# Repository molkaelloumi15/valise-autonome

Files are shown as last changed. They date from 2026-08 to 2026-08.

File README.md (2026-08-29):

# 🧳 Valise Autonome

Projet académique (2ᵉ année d'ingénieur, ENSIT, 2024–2025) réalisé en binôme (Molka Elloumi & Fakhri Menjli) : une valise connectée capable de **suivre automatiquement son propriétaire**, d'**éviter les obstacles**, et pilotable via une **application mobile Flutter**.

## 🎯 Fonctionnalités principales

| Fonctionnalité | Description |
|---|---|
| **Suivi autonome** | La valise détecte la position de son propriétaire en temps réel et le suit automatiquement. |
| **Navigation & évitement d'obstacles** | Détection et contournement des obstacles fixes et mobiles à l'aide de capteurs ultrasoniques. |
| **Mode manuel** | Contrôle manuel de la valise depuis l'application mobile. |
| **Notifications** | Alerte envoyée au smartphone en cas de perte de connexion avec la valise. |
| **Autonomie** | Batterie lithium-ion dimensionnée pour au moins 8h d'utilisation continue. |

## 🧠 Principe de fonctionnement

La valise embarque un microcontrôleur **ESP32** qui :
1. Estime la distance au smartphone du propriétaire à partir de la puissance du signal Wi-Fi (RSSI).
2. Mesure en parallèle la distance aux obstacles via un capteur ultrasonique.
3. Compare les deux mesures pour distinguer un vrai obstacle d'un simple éloignement du propriétaire, et ajuste le déplacement des moteurs en conséquence.
4. Expose ces données via un petit serveur web embarqué (mode point d'accès Wi-Fi), interrogé par l'application mobile.

## 🛠️ Stack technique

- **Firmware** : C++ (Arduino), ESP32, capteurs ultrasoniques HC-SR04, moteurs CC à engrenages FIT0564
- **Électronique** : PCB personnalisé conçu sous **KiCad**, prototypage sous **Proteus 8 ISIS**
- **Application mobile** : **Flutter** (architecture MVVM) — authentification, écran d'accueil, suivi en temps réel, réglages
- **Outils** : Arduino IDE, VS Code, KiCad

## 📂 Structure du dépôt

```
.
├── firmware/           # Code embarqué ESP32 (Arduino)
│   └── valise_autonome.ino
├── circuit/             # Conception électronique (KiCad)
│   ├── circuit.kicad_sch / .kicad_pcb / .kicad_pro
│   └── gerbers/          # Fichiers de fabrication (Gerber/drill)
├── mobile-app/          # Application Flutter (code source Dart)
│   ├── lib/
│   │   ├── main.dart
│   │   ├── screens/      # Login, Home, Profil, Réglages
│   │   └── services/     # Authentification, communication ESP32
│   ├── assets/
│   └── pubspec.yaml
└── docs/
    └── Valise_autonome.pdf   # Rapport de projet complet
```

## 📄 Documentation complète

Le rapport de projet complet (cahier des charges, étude de l'existant, architecture, choix techniques, résultats de tests) est disponible dans [`docs/Valise_autonome.pdf`](docs/Valise_autonome.pdf).

## 🚀 Pour reproduire le firmware

1. Ouvrir `firmware/valise_autonome.ino` dans l'Arduino IDE avec le support ESP32 installé.
2. Flasher la carte ESP32.
3. Se connecter au réseau Wi-Fi `Suitcase_AP` créé par la valise.
4. Lancer l'application Flutter (`mobile-app/`) pour piloter et suivre la valise.

---

*Projet réalisé dans le cadre de la formation d'ingénieur à l'ENSEA — Molka Elloumi, [LinkedIn](https://linkedin.com/in/molkaelloumi)*

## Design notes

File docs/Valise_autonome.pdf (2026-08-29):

# Rapport de Projet

de

# Deuxième année du premier semestre

Présenté et soutenu publiquement le 10/12/2024

Par

# ELLOUMI Molka MENJLI Fakhri

# Valise Autonome

### Membre du jury

### Monsieur

### Monsieur

### JEBRI Ayoub

### SIMOND Nicolas

### Année universitaire : 2024-2025

# Table des matières

Introduction générale | 1
Chapitre 1: | Gestion de Projet | 2
Chapitre 2: | Environnement de travail | 7

i

Table des matières | Table des matières
Chapitre 3: | ARCHITECTURE DU SYSTÈME | 15
Chapitre 4: | Réalisation logicielle | 18
Chapitre 5: | Réalisation matérielle | 27

ii

Table des matières | Table des matières
Bibliographie | 40

iii

# Table des figures

1.1 Diagramme de Gantt global de la deuxième phase du projet | | 6
2.1 Le microcontrôleur ESP32 | | 8
2.2 Moteurs CC à engrenages FIT0564 | | 9
2.3 Capteur ultrasonique SH04 | | 9
2.4 PCB personnalisé | 10
2.5 batterie 12v | 11
2.6 Proteus 8 ISIS | 11
2.7 Arduino IDE | 12
2.8 Flutter | 12
2.9 KiCad | 13
2.10 VS Code | 13
3.1 Schéma d’architecture globale du système | 15
4.1 Aperçu des résultats de tests | 21
4.2 Diagramme de cas d’utilisation de l’application mobile Flutter | 22
4.3 Architecture MVVM utilisée dans notre application Flutter | 23
4.4 Structure des fichiers de l’application Flutter | 24
4.5 Exemple de contrôle de saisie dans l’écran de connexion | 25
4.6 Interface principale de suivi (hors connexion) | 26
5.1 Arrêt du moteur lorsque PWM1 et PWM2 sont nuls | 28
5.2 Fonctionnement avec PWM1 actif | 28
5.3 Fonctionnement avec PWM2 actif | 28
5.4 Fonctionnement avec PWM1 et PWM2 actifs | 28

iv

Table des figures | Table des figures
5.5 Tableau récapitulatif du fonctionnement du notre controlleur | | 28
5.6 Simulation : Contrôle bidirectionnel du moteur | 30
5.7 Essai du circuit de contrôle moteur | 31
5.8 Routage du PCB sur KiCad | 32
5.9 largeur des pistes | 33
5.10 les tests | 34
5.11 Capteur ultrasonique SH04 | 36

v

# Introduction générale

Le projet de valise autonome vise à répondre aux besoins des voyageurs dans des environnements

variés comme les aéroports, les gares ou les trottoirs. Cette innovation cherche à réduire les

efforts physiques liés au transport des bagages tout en améliorant la mobilité et le confort des

utilisateurs. Avec l’évolution des technologies de navigation et de suivi, ce projet explore une

solution autonome qui combine électronique avancée et intelligence embarquée pour offrir une

expérience pratique et innovante.

### Chapitre 1

# Gestion de Projet

## Introduction

Ce chapitre du projet présente la gestion de notre travail. Nous y détaillons tout d’abord le

cahier des charges, suivi d’une étude des solutions existantes sur le marché, qui nous a permis

de nous inspirer tout en identifiant leurs limites. Nous proposons ensuite notre solution et

terminons par l’élaboration du diagramme de Gantt pour la première phase du projet, puis

celui relatif à la seconde phase.

## 1 Cahier des Charges

Dans cette section, nous allons parler du cahier des charges. À partir du sujet proposé, nous

avons pu déterminer ses fonctionnalités obligatoires et élaborer un cahier des charges servant

de référence pour notre travail. Nous avons également élaboré le tableau ci-dessous. Ce tableau

comporte les fonctionnalités, leur expression, les critères, et les moyens de contrôle.

— Expression : il s’agit de l’explication de la fonctionnalité.

— Critères : ils désignent les conditions ou exigences spécifiques que la fonctionnalité doit

remplir pour être considérée comme réussie. Un critère représente ce qui est attendu

comme résultat pour vérifier la fonctionnalité.

— Moyens de contrôle : ce sont les outils ou méthodes permettant de s’assurer que les

critères sont respectés.

Chapitre 1. Gestion de Projet | 2. Étude de l’Existant
Fonctionnalité (FP) | Expression | Critères | Moyen de Contrôle
FP1 : Suivi Au-tonome | Permettre à la valise de suivre automatiquement son propriétaire. | La valise doit détec-ter la position du propriétaire en temps réel. | Capteurs ultraso-niques, un module wifi intégré dans la carte ESP32, et les moteurs.
FP2 : Naviga-tion | Naviguer de manière auto-nome dans différents envi-ronnements. | Capacité à détecter et à éviter des obstacles immobiles et mobiles. | Capteurs ultraso-niques, un module wifi intégré dans la carte ESP32 et les moteurs.
FP3 : Mode Manuel | Permettre le contrôle ma-nuel de la valise. | Le mode manuel doit être activé facilement et rapidement. | Interface utilisateur (boutons, applica-tion).
FP4 : Notifica-tions | Envoyer des alertes au pro-priétaire en cas de perte de connexion. | Notification sur smartphone en cas de perte de connexion. | WIFI
FP5 : Autono-mie de la Bat-terie | Fonctionner sans recharge fréquente. | Autonomie d’au moins 8 heures en utilisation normale. | Batterie lithium-ion

Table 1.1 – Spécifications des fonctionnalités principales du projet

## 2 Étude de l’Existant

Après des recherches, nous avons pu identifier trois solutions similaires à notre projet. Bien

que nous n’ayons pas trouvé de références techniques, nous avons trouvé des descriptions des

technologies utilisées, ce qui nous a aidés à mieux comprendre. Voici un tableau qui donne un

aperçu de ces solutions en présentant précisément les technologies utilisées, leurs avantages et

leurs inconvénients.

Solution | Technologie Utili-sée | Avantages | Inconvénients
Valise Ovis | Suivi par caméra et IA | - Suivi précis et intelli-gent - Bonne navigation dans les environnements ou-verts | - Très coûteuse (prix élevé). - Autonomie limitée (batterie).

Chapitre 1. Gestion de Projet | 3. Limites des Solutions Existantes
Valise Travel-mate | Suivi par Blue-tooth (RSSI) | - Faible coût relatif - Facile à mettre en œuvre | - Navigation imprécise en cas d’obstacles. - Portée limitée de la connexion Bluetooth.
Valise Cowaro-bot | Capteurs ultraso-niques et LiDAR | - Excellente détection d’obstacles - Bonne autonomie de batterie | - Lourde et coûteuse. - Complexité dans la maintenance.

## 3 Limites des Solutions Existantes

À travers cette analyse, nous constatons que :

— Le coût élevé des solutions comme Ovis ou Cowarobot limite leur accessibilité.

— Les technologies basées uniquement sur le Bluetooth montrent des limites en termes de

portée et de précision.

— Les systèmes complexes intégrant des caméras IA ou LiDAR augmentent la consomma-

tion énergétique, ce qui réduit l’autonomie de la batterie.

Nous avons pu, à travers ces observations, élaborer notre solution en tenant compte de nos

contraintes, tout en envisageant d’apporter des améliorations et des optimisations. Notre solu-

tion doit :

— Utiliser des technologies abordables .

— Maintenir un coût réduit tout en respectant les contraintes techniques et budgétaires.

— Assurer une autonomie énergétique satisfaisante en intégrant une batterie adaptée.

## 4 Proposition de Notre Solution

Pour mieux présenter ce que nous souhaitons réaliser, nous avons élaboré un tableau qui résume

comment chaque fonctionnalité discutée dans le cahier des charges sera satisfaite technologique-

ment à travers la solution technologique proposée, ainsi qu’une justification brève de ce choix,

tout en respectant une contrainte budgétaire stricte.

Chapitre 1. Gestion de Projet5. Analyse Comparative : Solutions Existantes vs Notre Solution

Composant | Technologie Choisie | Justification
Suivi du propriétaire | Wi-Fi (RSSI) | Solution abordable et plus ro-buste que Bluetooth pour une communication fiable.
Détection d’obstacles | Capteurs ultraso-niques HC-SR04 | Solution abordable et fiable pour la navigation et la détection d’obstacles.
Navigation et contrôle | Microcontrôleur ESP32 | Intègre Wi-Fi pour la commu-nication et Bluetooth comme option secondaire, à faible coût.
Propulsion | Moteurs CC avec un contrôleur | Économique, fiable et facile à contrôler.
Alimentation | Batterie lithium-ion rechargeable | Offre une bonne autonomie pour une utilisation prolongée avec un poids réduit.

Table 1.3 – Composants et technologies choisis pour la solution

## 5 Analyse Comparative : Solutions Existantes vs Notre Solu-

## tion

Finalement, nous avons réalisé ce tableau récapitulatif qui met en valeur ce que nous avons

amélioré par rapport aux autres solutions.

Critère | Valise Ovis | Valise Travel-mate | Notre Solution
Technologie de Suivi | IA + Caméra | Bluetooth | Wifi (RSSI)
Technologie de Navi-gation | Caméras/LiDAR | Capteurs ba-siques | Capteurs ultra-soniques HC-SR04
Coût | Très élevé | Modéré | Abordable
Autonomie | Moyenne | Bonne | Optimisée avec batterie Li-Ion
Précision de Suivi | Élevée | Faible | Moyenne (amé-liorable par op-timisation)

Chapitre 1. Gestion de Projet | 6. Diagramme de Gantt

Facilité de mise en

œuvre

Complexe | Simple | Simple

## 6 Diagramme de Gantt

Le diagramme de Gantt est un outil de planification visuelle permettant de structurer les

tâches d’un projet dans le temps. Pour la seconde phase de notre projet, nous avons élaboré un

diagramme global afin de définir les différentes étapes prévues et organiser leur déroulement.

Cependant, en raison de divers problèmes techniques et de contraintes rencontrés en cours de

réalisation, nous n’avons pu mener à bien que les trois dernières tâches planifiées.

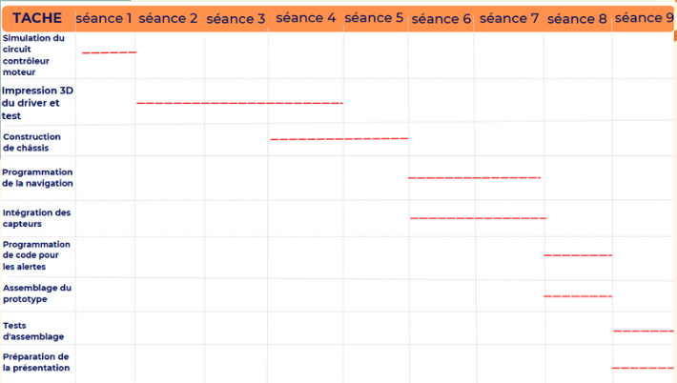
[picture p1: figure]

Figure 1.1 – Diagramme de Gantt global de la deuxième phase du projet

## Conclusion

Ce chapitre a permis de présenter les grandes lignes de notre projet, d’introduire notre cahier des

charges ainsi que notre réflexion autour de la solution retenue. Nous avons également expliqué

notre planification, tout en précisant les limites rencontrées lors de la mise en œuvre. Le chapitre

suivant détaillera l’environnement matériel et logiciel utilisé pour concrétiser notre solution.

### Chapitre 2

# Environnement de travail

## Introduction

Ce chapitre décrit les différents environnements de travail, tant matériels que logiciels, qui

ont été nécessaires à la réalisation de ce projet. Ces environnements ont été soigneusement

sélectionnés pour répondre aux exigences techniques et fonctionnelles de la solution envisagée.

## 1 Environnement matériel

Pour la conception et la réalisation de la valise autonome, plusieurs éléments matériels ont été

utilisés :

### 2.1.1 Le microcontrôleur ESP32

Le microcontrôleur ESP32 a été choisi pour ses performances élevées en termes de traitement et

de connectivité. Il dispose d’un processeur double cœur, d’une connectivité Wi-Fi et Bluetooth

intégrée, ce qui le rend idéal pour gérer les communications sans fil et les interactions avec les

capteurs et les moteurs. Sa faible consommation énergétique et son large écosystème de support

logiciel en font un choix fiable pour les applications embarquées.

Chapitre 2. Environnement de travail | 1. Environnement matériel

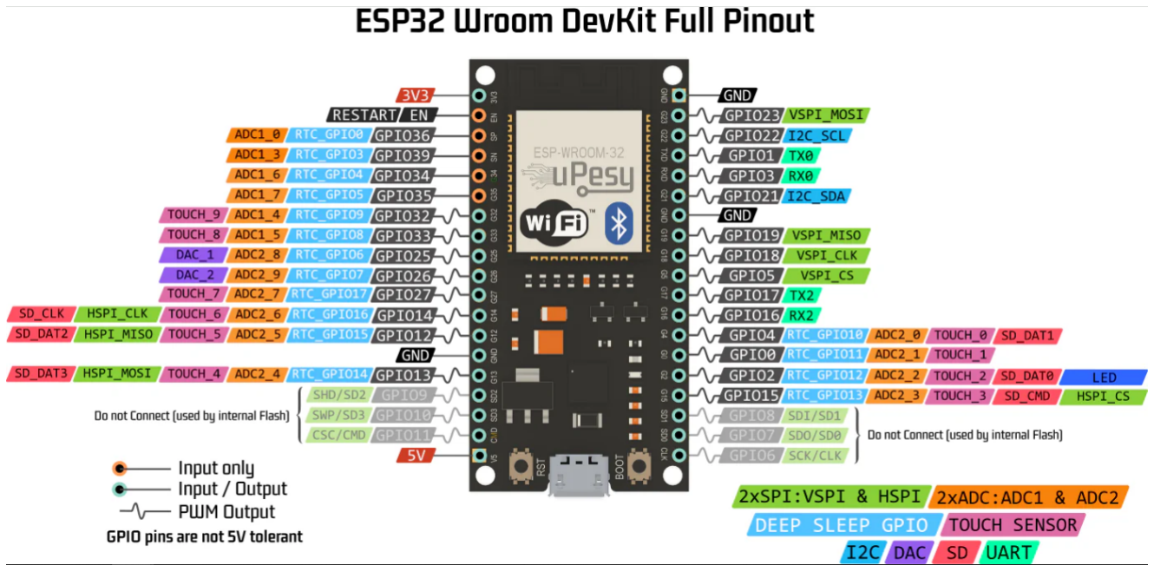
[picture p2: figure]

Figure 2.1 – Le microcontrôleur ESP32

### 2.1.2 Moteurs CC à engrenages FIT0564

Ces moteurs à courant continu avec réducteur intégré offrent une combinaison idéale de puis-

sance et de précision. Le réducteur permet de fournir un couple élevé, nécessaire pour déplacer

la valise, tout en maintenant une vitesse contrôlée. Leur robustesse et leur durabilité en font

un choix adapté pour une utilisation prolongée dans des conditions variées.

Table 2.1 – Étude mathématique pour le choix du moteur

Étape | Prototype (1 kg) | Cas réel (23 kg)
1. Force exercée par la charge | f=m*g =9.81 N | f = m ∗ g = 225.63 N
2. Couple | C = f ∗ r = 0.4905 Nm | C = f ∗ r = 11.2815Nm
3. Vitesse angulaire | N = 2π0.05 ≈ 134.5 tr/min 1.460 N = 2π
4. Puissance | P = 6.91 W | P = 159 W
5. Courant | I = V = P 6.91 12 ≈ 0.7 A | I = V = P 159 48 ≈ 3 A
6. Durée de fonction-nement | capacité 9 t = courant = 1.15 ≈ 8 heures | capacité 18 t = courant = 3 ≈ 6 heures
60 ≈ 14.1 rad/s | N =

1.460
2π0.05 ≈ 134.5 tr/min

Les calculs ci-dessus ont été réalisés afin de choisir le moteur adapté en prenant en compte la

force, le couple, la vitesse angulaire, la puissance nécessaire et l’autonomie énergétique.

Chapitre 2. Environnement de travail | 1. Environnement matériel

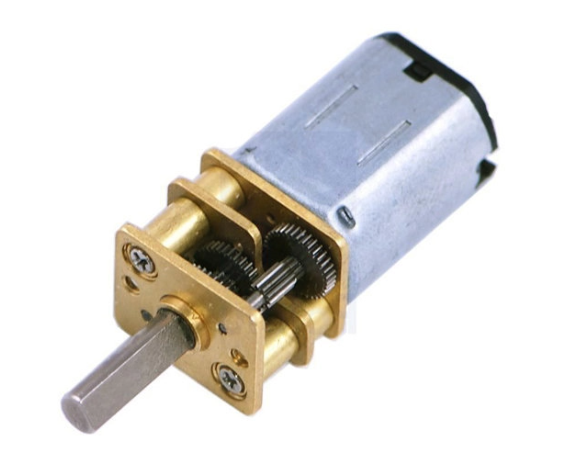
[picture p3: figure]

Figure 2.2 – Moteurs CC à engrenages FIT0564

### 2.1.3 Capteur ultrasonique SH04

Ce capteur est utilisé pour mesurer les distances grâce à l’émission et la réception d’ondes

ultrasoniques. Avec une portée précise allant jusqu’à plusieurs mètres, il permet à la valise de

détecter et d’éviter les obstacles tout en suivant son propriétaire. Sa simplicité d’intégration et

sa fiabilité en font un composant essentiel pour la navigation autonome.

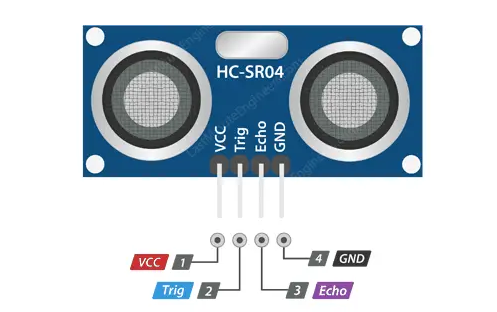
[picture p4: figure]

Figure 2.3 – Capteur ultrasonique SH04

### 2.1.4 Contrôleur de moteur (PCB personnalisé)

Le contrôleur de moteur est un circuit imprimé conçu spécifiquement pour ce projet. Il intègre

un hacheur à quatre quadrants, permettant de contrôler à la fois la vitesse et le sens de rotation

des moteurs. Ce circuit a été conçu pour offrir une grande précision et une efficacité énergétique

optimale. Sa conception sur mesure garantit une compatibilité parfaite avec les moteurs et les

autres composants du système.

Chapitre 2. Environnement de travail | 1. Environnement matériel

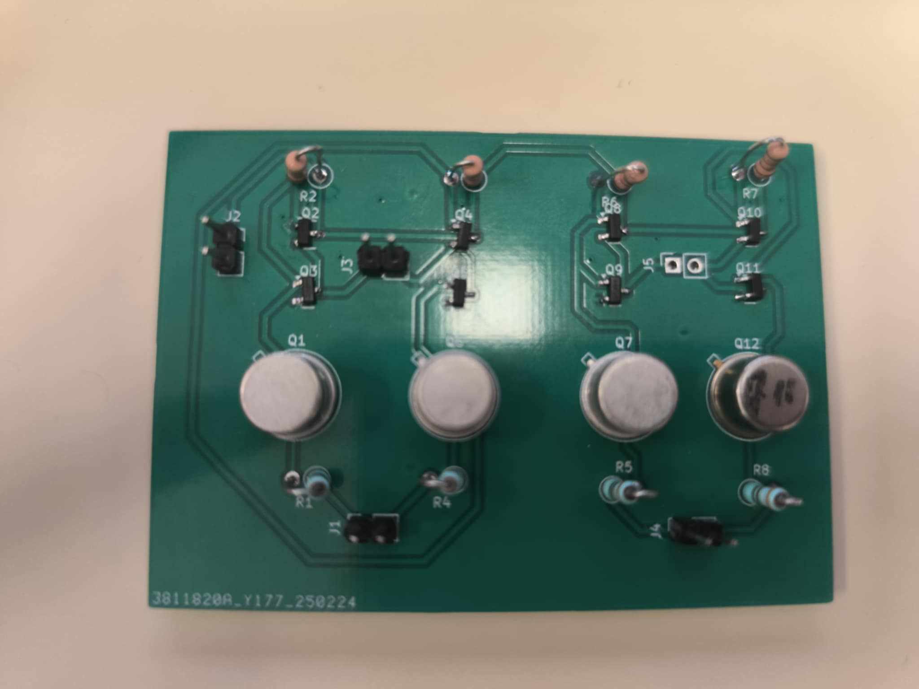
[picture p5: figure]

Figure 2.4 – PCB personnalisé

### 2.1.5 Alimentation

L’alimentation de la valise autonome repose sur deux systèmes distincts : une batterie Li-ion

pour alimenter la carte ESP32 et les capteurs, et une batterie 12V pour les moteurs.

Batterie Li-ion

Cette batterie, d’une capacité suffisante, alimente la carte ESP32 et les capteurs. Elle est

choisie pour sa haute densité énergétique, permettant une autonomie prolongée. Un régulateur

de tension permet de convertir la sortie de la batterie Li-ion (3.7V) en 3.3V pour l’ESP32.

Batterie 12V

Elle est utilisée pour alimenter les moteurs et le contrôleur de moteur. Cette batterie est di-

mensionnée pour fournir une autonomie suffisante lors des déplacements de la valise.

Chapitre 2. Environnement de travail | 2. Environnement logiciel

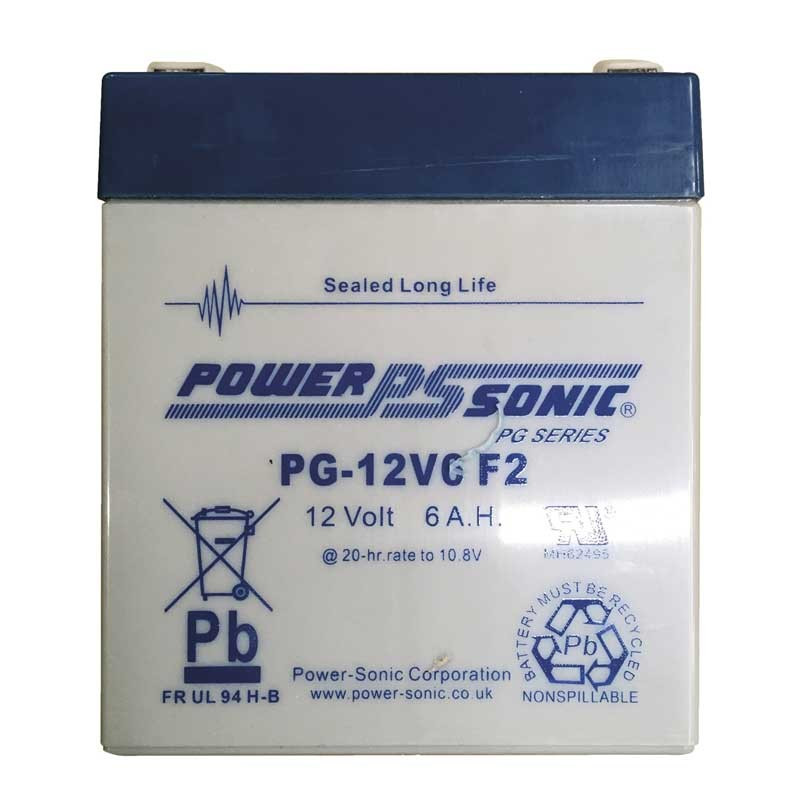
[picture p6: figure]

Figure 2.5 – batterie 12v

## 2 Environnement logiciel

Le développement et la simulation du projet ont nécessité l’utilisation de deux outils logiciels :

### 2.2.1 Proteus 8 ISIS

Cet outil a été employé pour la conception et la simulation des circuits électroniques. Grâce à sa

capacité de simuler des composants en temps réel, il a permis de tester et d’optimiser le schéma

du contrôleur de moteur avant sa fabrication. La simulation a inclus des tests de tension, de

courant et de réponse dynamique des circuits.

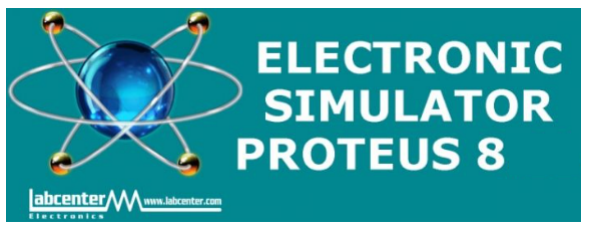
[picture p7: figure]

Figure 2.6 – Proteus 8 ISIS

Chapitre 2. Environnement de travail | 2. Environnement logiciel

### 2.2.2 Arduino IDE

L’Arduino Integrated Development Environment (IDE) a été utilisé pour écrire, compiler et

téléverser le code sur l’ESP32. Cet outil propose une interface intuitive qui simplifie le déve-

loppement grâce à une vaste bibliothèque de fonctions prêtes à l’emploi, comme la gestion des

capteurs, des moteurs et de la connectivité. L’IDE offre également un moniteur série intégré,

utile pour le débogage en temps réel des fonctionnalités du système.

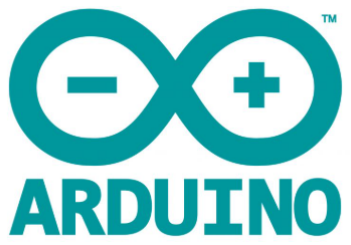
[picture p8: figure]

Figure 2.7 – Arduino IDE

### 2.2.3 Flutter

Flutter est un framework open source développé par Google permettant de créer des applications

mobiles multiplateformes. Dans le cadre de ce projet, Flutter a été utilisé pour développer une

application mobile Android servant d’interface de communication avec la valise autonome.

Grâce à son langage Dart et son environnement de développement intégré, Flutter a permis de

concevoir des interfaces utilisateur modernes et réactives.

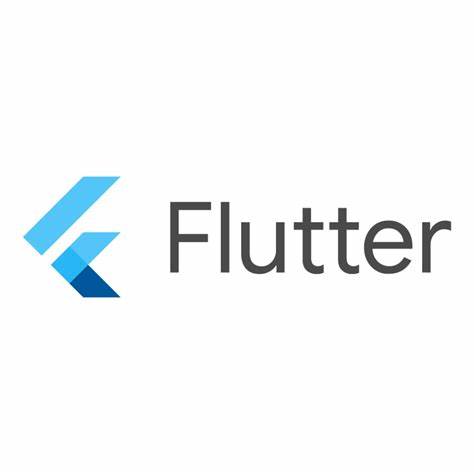
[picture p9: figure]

Figure 2.8 – Flutter

Chapitre 2. Environnement de travail | 2. Environnement logiciel

### 2.2.4 KiCad

KiCad est un logiciel de conception assistée par ordinateur (CAO) libre utilisé pour concevoir

des circuits imprimés (PCB). Dans notre projet, KiCad a été utilisé pour la réalisation du

schéma électrique et du routage du PCB du contrôleur moteur bidirectionnel.

Figure 2.9 – KiCad

### 2.2.5 Visual Studio Code (VS Code)

Visual Studio Code est un éditeur de code multiplateforme largement utilisé pour le dévelop-

pement embarqué. Dans notre projet, il a été utilisé pour écrire et organiser le code destiné

à l’ESP32, notamment à l’aide de l’extension PlatformIO, qui offre une meilleure gestion des

projets et des dépendances que l’IDE Arduino.

VS Code a également permis d’éditer les scripts en Dart pour Flutter, de tester les requêtes

HTTP, et de configurer les paramètres réseau du projet. Son interface moderne et ses nom-

breuses extensions ont grandement facilité le processus de développement et de débogage.

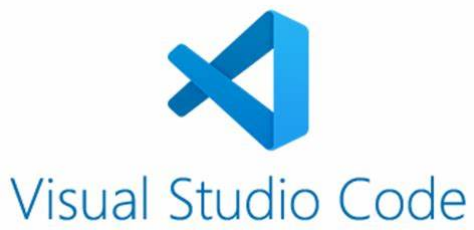
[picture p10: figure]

Figure 2.10 – VS Code

## Conclusion

Nous avons bien décrit dans ce chapitre l’environnement de travail mis en place pour ce projet,

qui repose sur une combinaison d’équipements matériels robustes et d’outils logiciels perfor-

Chapitre 2. Environnement de travail | 2. Environnement logiciel

mants. Dans le prochain chapitre, nous aborderons l’architecture de notre valise.

### Chapitre 3

# ARCHITECTURE DU SYSTÈME

## Introduction

Ce chapitre présente l’architecture globale de la solution technique mise en place pour la réa-

lisation de la valise autonome. Nous y décrivons l’organisation matérielle et logicielle, les flux

de communication entre les différents modules, ainsi que le fonctionnement global du système.

Une attention particulière est portée à l’interaction avec l’utilisateur, qui reçoit en temps réel

des informations cruciales via l’application mobile Flutter.

## 1 Schéma d’ensemble

Le diagramme suivant illustre l’interaction entre les principaux composants matériels et leur

rôle dans le fonctionnement de la valise autonome.

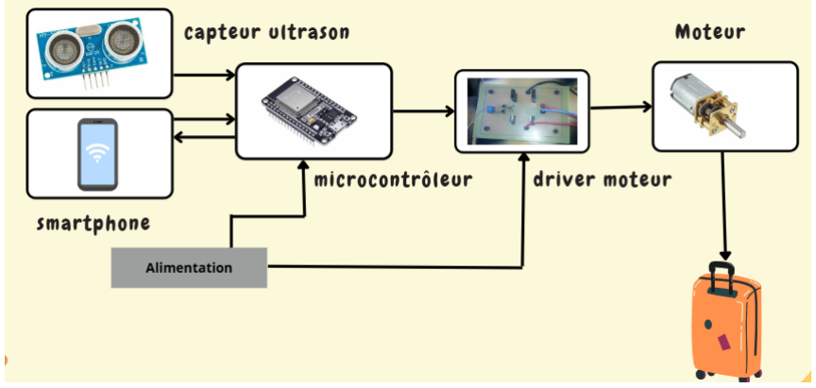
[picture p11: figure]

Figure 3.1 – Schéma d’architecture globale du système

Chapitre 3. ARCHITECTURE DU SYSTÈME | 2. Flux de Communication

Les éléments principaux du système sont :

— Microcontrôleur (ESP32) : Coordonne le système en traitant les données des capteurs

et en contrôlant les moteurs.

— Capteurs ultrasoniques : Détectent les obstacles à proximité et transmettent les dis-

tances au microcontrôleur.

— Contrôleur de moteur : Régule la puissance et la direction des moteurs selon les ins-

tructions du microcontrôleur.

— Moteurs à engrenages CC : Assurent le mouvement et la direction de la valise.

— Connexion WiFi : Permet la communication entre la valise et le smartphone de l’utili-

sateur.

— Batterie lithium-ion : Fournit l’énergie nécessaire au fonctionnement des composants.

## 2 Flux de Communication

Les flux de données entre les différents composants garantissent le fonctionnement global du

système. Voici la séquence des échanges :

1. Capteurs vers Microcontrôleur : Les capteurs ultrasoniques mesurent les distances aux

obstacles et envoient les informations au microcontrôleur (ESP32).

2. Microcontrôleur vers Contrôleur de Moteur : Le microcontrôleur analyse les données

reçues et envoie des instructions précises au contrôleur pour ajuster la vitesse et la

direction des moteurs.

3. Contrôleur de Moteur vers Moteurs : Le contrôleur de moteur régule la puissance

fournie aux moteurs pour exécuter les commandes du microcontrôleur (mouvement, arrêt

ou changement de direction).

4. Microcontrôleur vers Application Smartphone : Le microcontrôleur utilise la connexion

WiFi pour transmettre des informations essentielles à l’application Flutter installée sur

le smartphone de l’utilisateur. Cette communication inclut :

— le statut de la connexion entre la valise et l’utilisateur (valise connectée ou perdue),

— la distance estimée entre la valise et le smartphone (via RSSI),

— la détection éventuelle d’un obstacle (via le capteur ultrasonique).

L’application affiche ces informations de manière intuitive, permettant à l’utilisateur

de réagir rapidement en cas de problème et de suivre la position de la valise en toute

simplicité.

Chapitre 3. ARCHITECTURE DU SYSTÈME | 3. Fonctionnement Global de la Valise

## 3 Fonctionnement Global de la Valise

L’algorithme global qui régit le fonctionnement de la valise peut être décrit en quatre étapes

principales :

1. Détection et Connexion WiFi : La valise établit une connexion WiFi avec le smartphone

de l’utilisateur. Le microcontrôleur récupère en continu les informations sur la densité

du signal WiFi pour estimer la position relative du propriétaire.

2. Suivi de la Direction : Si le signal WiFi diminue, la valise détecte qu’elle s’éloigne et

ajuste sa trajectoire en conséquence. Les moteurs à engrenages CC sont commandés pour

corriger la direction.

3. Gestion des Obstacles : Les capteurs ultrasoniques mesurent en temps réel les distances

avec les obstacles environnants. En cas de détection, le microcontrôleur ajuste les moteurs

pour éviter la collision.

4. Mise à Jour de la Direction : La valise combine les informations des capteurs et du

signal WiFi pour corriger continuellement sa trajectoire, assurant ainsi un suivi fluide et

sécurisé.

## Conclusion

Ce chapitre a présenté l’architecture globale du système, en mettant en lumière les interactions

entre les composants matériels, logiciels, et l’utilisateur. L’intégration de l’application Flutter

assure une communication bidirectionnelle efficace, permettant à la valise d’agir et d’informer

l’utilisateur en temps réel sur sa position, la connexion et les obstacles. Le chapitre suivant

abordera la réalisation logicielle du projet.

### Chapitre 4

# Réalisation logicielle

## Introduction

Ce chapitre détaille le développement logiciel du projet, depuis la programmation embarquée

sur l’ESP32 jusqu’à la création de l’application mobile Flutter. Nous y expliquons les logiques

de traitement, de communication et d’affichage mises en place.

## 1 Programmation embarquée de l’ESP32

La programmation de la carte ESP32 constitue le cœur du système embarqué de la valise

autonome. Elle permet à la valise de percevoir son environnement, de prendre des décisions de

navigation, et de transmettre les informations nécessaires à l’application mobile Flutter. Les

principales fonctionnalités mises en œuvre sont les suivantes :

### 4.1.1 Lecture des capteurs

Deux types de capteurs sont utilisés :

— Le capteur ultrasonique Les données du capteur ultrasonique sont récupérées régulière-

ment afin de détecter les obstacles et ajuster la trajectoire.

— Le signal RSSI WiFi est utilisé pour estimer la distance entre le smartphone de l’utili-

sateur et la valise, à partir de la puissance du signal WiFi reçu.

Chapitre 4. Réalisation logicielle | 1. Programmation embarquée de l’ESP32

### 4.1.2 Estimation de la distance via le RSSI

Le RSSI (Received Signal Strength Indicator) est un indicateur de la puissance du signal WiFi

reçu par l’ESP32. Il est exprimé en dBm. Une valeur plus proche de zéro indique un signal plus

fort. Dans notre projet, il est utilisé pour :

— Estimer la distance entre la valise et le smartphone du propriétaire.

— Déterminer si la valise doit s’approcher, rester sur place, ou signaler une perte de

connexion.

Formule de calcul de distance :

d = 10

A−RSSI
10n | (4.1)

où :

— d : distance en mètres,

— A : RSSI à 1 mètre,

— n : facteur d’atténuation (selon l’environnement),

— RSSI : signal mesuré (en dBm).

### 4.1.3 Logique de navigation intelligente

La logique de navigation de la valise repose sur l’interprétation croisée des données issues de

deux sources : le signal RSSI (Received Signal Strength Indicator) et le capteur ultrasonique.

L’objectif est de permettre à la valise de suivre son utilisateur tout en évitant les obstacles, de

manière autonome et réactive.

Voici le fonctionnement général de l’algorithme embarqué :

— Lorsque la valise est suffisamment proche de l’utilisateur (selon la valeur du RSSI), elle

reste immobile.

— Si le RSSI indique un éloignement (signal plus faible), la valise se met en mouvement

pour réduire la distance avec son propriétaire.

— Pendant le déplacement, la valise utilise le capteur ultrasonique pour détecter tout obs-

tacle présent sur son trajet.

— Si un obstacle est détecté, la valise interrompt immédiatement son mouvement et ajuste

sa direction pour le contourner.

Chapitre 4. Réalisation logicielle | 1. Programmation embarquée de l’ESP32

### 4.1.4 Logique de détection d’obstacles avec tolérance

Afin d’éviter les fausses alertes lors de la détection d’obstacles, nous avons constaté que le

capteur ultrasonique pouvait parfois interpréter de manière incorrecte certains éléments comme

étant des obstacles, alors qu’ils ne représentent pas une gêne réelle. Cela peut notamment se

produire dans les cas suivants :

— L’utilisateur lui-même (par exemple, une main ou une jambe passant devant le capteur)

est détecté comme un obstacle,

— Un objet est détecté à une distance bien supérieure à celle entre la valise et l’utilisateur

(selon le RSSI),

— Un obstacle est situé à côté de l’utilisateur mais ne se trouve pas sur la trajectoire de la

valise.

Pour résoudre ces problèmes, nous avons mis en place une logique de filtrage basée sur la

comparaison entre :

— la distance estimée par le signal RSSI (qui indique à quelle distance se trouve l’utili-

sateur). et la distance mesurée par le capteur ultrasonique (qui identifie les obstacles

physiques).

L’idée est simple : si un obstacle est détecté, mais qu’il est plus éloigné que l’utilisateur lui-

même, alors il n’est pas considéré comme prioritaire. De plus, une marge de tolérance est

définie afin d’ignorer les différences minimes de distance dues à des erreurs de mesure ou à des

mouvements passagers.

Cette logique est illustrée dans le code embarqué suivant :

— Le signal RSSI est converti en distance estimée à l’aide de la formule standard de pro-

pagation de signal.

— La fonction mesurerDistance() calcule la distance réelle mesurée par le capteur ultra-

sonique.

— On considère qu’il y a un véritable obstacle uniquement si :

obstacleDistance < rssiDistance − TOLERANCE

— Si cette condition n’est pas remplie, le capteur est soit perturbé, soit c’est une fausse

alerte, et l’information est ignorée dans la réponse JSON envoyée à l’application Flutter.

Cette logique permet à la valise de naviguer de manière fluide tout en assurant un suivi fiable

de l’utilisateur, même dans des environnements dynamiques.

Chapitre 4. Réalisation logicielle | 2. Application mobile Flutter

### 4.1.5 Tests

L’image ci-dessous montre un extrait des résultats issus du moniteur série de l’ESP32 lors d’un

test de détection d’obstacles. On y observe les valeurs mesurées en temps réel par le système :

— La distance estimée entre l’utilisateur et la valise, calculée à partir du RSSI, est en

moyenne de 12.59 cm, avec une légère augmentation à 14.13 cm à deux reprises.

— La distance mesurée par le capteur ultrasonique reste stable autour de 9.45 cm, ce qui

indique la présence constante d’un objet situé devant la valise.

Le système considère l’obstacle comme réel et affiche cette détection dans le moniteur série par

le message : –> real obstacle .

Ce test démontre que la logique de filtrage mise en place fonctionne correctement et permet de

détecter efficacement un obstacle légitime tout en évitant les fausses alertes dues à des objets

situés en dehors de la trajectoire ou trop proches du propriétaire.

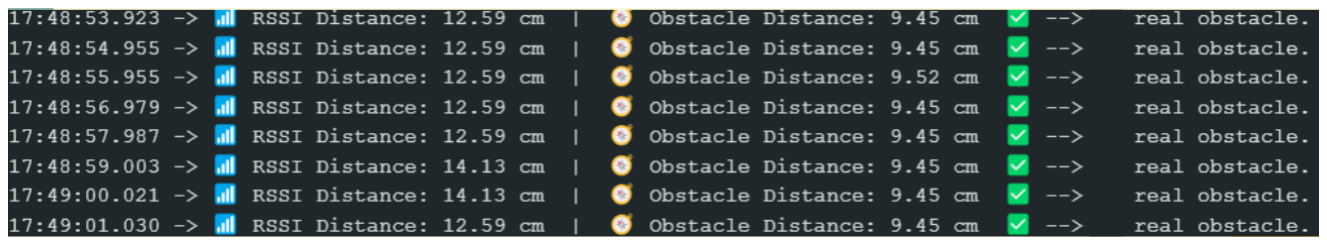
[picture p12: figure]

Figure 4.1 – Aperçu des résultats de tests

## 2 Application mobile Flutter

### 4.2.1 Présentation générale et fonctionnalités

L’application mobile a été développée avec Flutter, un framework open source de Google per-

mettant de créer des interfaces modernes, multiplateformes et réactives.

Elle a pour but de permettre à l’utilisateur :

— de savoir si la valise est connectée ou non,

— de connaître la distance entre lui et la valise (calculée à partir du RSSI),

— d’être alerté si un obstacle est détecté,

— de consulter ces informations en temps réel,

— de se déconnecter facilement de l’interface.

Chapitre 4. Réalisation logicielle | 2. Application mobile Flutter

Ces fonctions sont accessibles via une interface fluide, organisée autour d’un écran de connexion

et d’un tableau de bord principal.

Le diagramme ci-dessous illustre les cas d’utilisation associés à l’application :

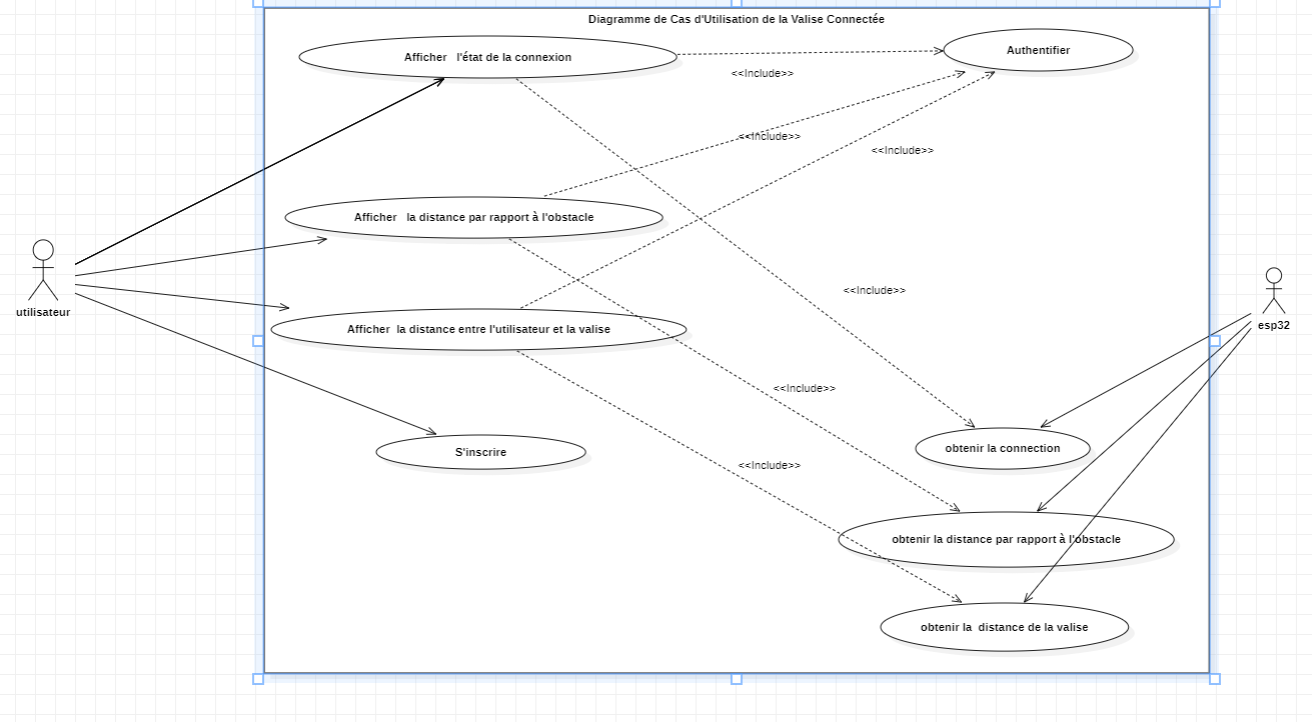
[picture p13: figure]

Figure 4.2 – Diagramme de cas d’utilisation de l’application mobile Flutter

### 4.2.2 Architecture et logique de communication

L’application repose sur une architecture inspirée du modèle MVVM (Model-View-ViewModel),

adaptée à la structure de Flutter :

— Model : données reçues depuis l’ESP32 via HTTP (au format JSON),

— ViewModel : logique de traitement et d’appel réseau (dans les fichiers esp32_service.dart),

— View : affichage des données via les interfaces (home_screen.dart, login_screen.dart).

Chapitre 4. Réalisation logicielle | 2. Application mobile Flutter

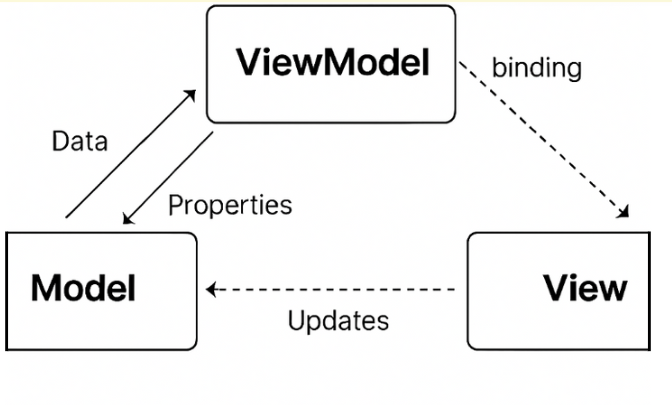
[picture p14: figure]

Figure 4.3 – Architecture MVVM utilisée dans notre application Flutter

Bien que notre architecture suive le principe général du modèle MVVM, nous n’avons pas

implémenté de couche Model distincte sous forme de classes de données. Les informations

reçues depuis l’ESP32, au format JSON, sont directement traitées dans les services (notamment

dans esp32_service.dart), sans être encapsulées dans des objets métiers spécifiques. Ainsi,

notre structure se rapproche davantage d’une séparation entre View (interfaces utilisateur) et

Service (logique et appels réseau), sans réelle couche Model formelle.

Chapitre 4. Réalisation logicielle | 2. Application mobile Flutter

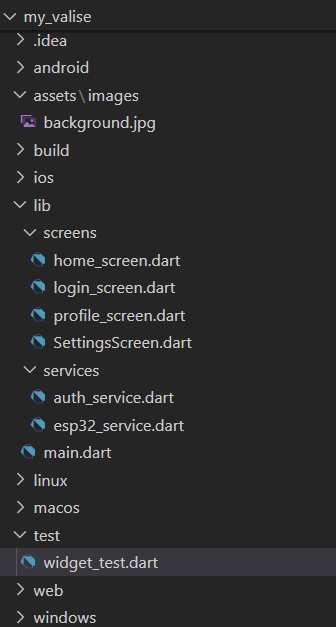
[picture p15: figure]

Figure 4.4 – Structure des fichiers de l’application Flutter

La communication entre l’application et l’ESP32 se fait via des requêtes HTTP GET envoyées

régulièrement vers les endpoints suivants :

— ‘/status‘ : statut de connexion.

— ‘/distance‘ : distance estimée via RSSI.

— ‘/obstacle‘ : distance mesurée par le capteur ultrasonique.

L’ESP32, fonctionnant en mode Point d’Accès, répond en JSON avec les valeurs actualisées.

Ces données sont ensuite traitées et affichées dynamiquement.

### 4.2.3 Interface utilisateur

L’interface est constituée de deux écrans principaux :

Chapitre 4. Réalisation logicielle | 2. Application mobile Flutter

— Écran de connexion L’utilisateur est invité à saisir ses identifiants. Un message d’erreur

s’affiche si les champs sont invalides.

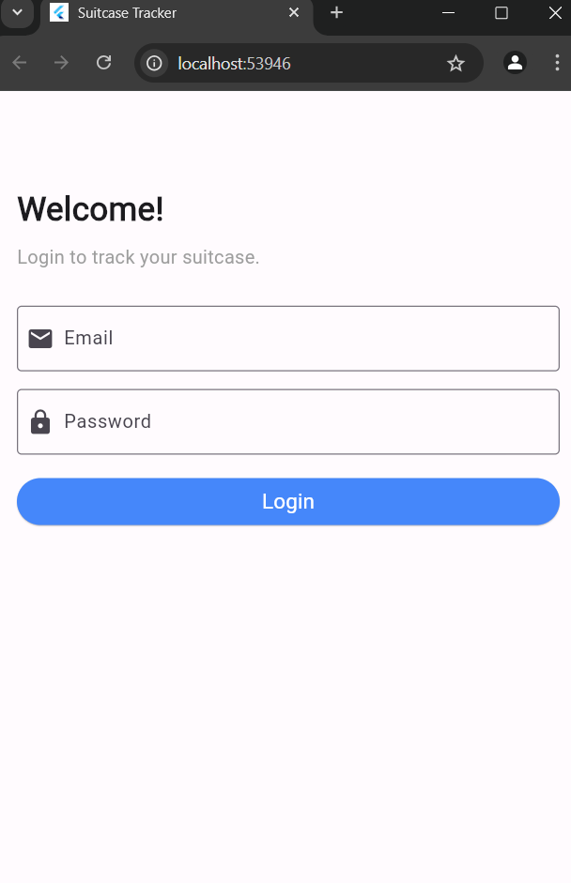
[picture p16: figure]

Figure 4.5 – Exemple de contrôle de saisie dans l’écran de connexion

— Écran principal (Home) Une fois connecté, l’utilisateur accède aux informations en temps

réel :

— distance de la valise,

— état de la connexion,

— présence d’obstacles.

Note : L’interface affichée ici correspond à un cas sans connexion active. L’interface en

condition réelle a été montrée lors de la démonstration, le matériel n’étant pas disponible au

moment de la rédaction.

Chapitre 4. Réalisation logicielle | 2. Application mobile Flutter

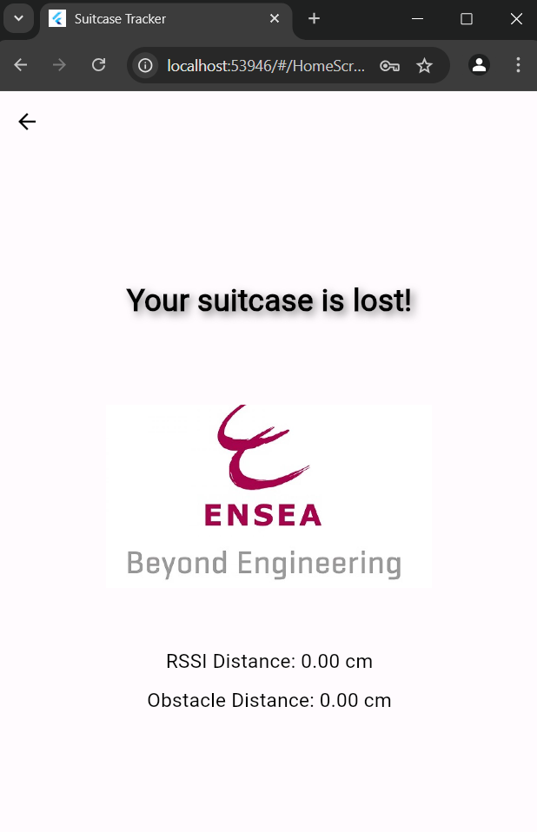
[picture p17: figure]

Figure 4.6 – Interface principale de suivi (hors connexion)

— Déconnexion L’utilisateur peut quitter l’application à l’aide de la flèche en haut à gauche.

### Chapitre 5

# Réalisation matérielle

## Introduction

Dans ce chapitre, le travail a principalement porté sur la conception d’un circuit électronique,

la gestion de la motorisation via un PCB dédié au contrôle des moteurs, ainsi que l’intégration

des capteurs nécessaires au bon fonctionnement du système.

## 1 Le contrôleur de moteur

### 5.1.1 Fonctionnement du contrôleur

Le contrôleur moteur utilise un hacheur à quatre quadrants pour gérer la vitesse et le sens de

rotation. Les signaux PWM (Pulse Width Modulation) sont appliqués aux entrées de contrôle

pour ajuster précisément la puissance transmise aux moteurs.

Les images ci-dessous montrent le fonctionnement du contrôleur en fonction des signaux d’entrée

PWM1 et PWM2.

Chapitre 5. Réalisation matérielle | 1. Le contrôleur de moteur

Figure 5.1 – Arrêt du moteur lorsque PWM1 et PWM2 sont nuls

Figure 5.2 – Fonctionnement avec PWM1 actif

Figure 5.3 – Fonctionnement avec PWM2 actif

Figure 5.4 – Fonctionnement avec PWM1 et PWM2 actifs

Les images ci-dessous montrent le tableau récapitulatif du fonctionnement du notre controlleur :

Figure 5.5 – Tableau récapitulatif du fonctionnement du notre controlleur

Chapitre 5. Réalisation matérielle | 1. Le contrôleur de moteur

### 5.1.2 Dimensionnement du Contrôleur Moteur

Composants Sélectionnés

Les composants principaux sont listés ci-dessous avec leurs caractéristiques respectives, suivant

le modèle de tableau fourni :

Table 5.1 – Caractéristiques des composants du contrôleur moteur

Composant | Caractéristiques
Motoréducteur FIT0564 | Tension nominale : 12 V Courant nominal : 1 A Courant maximal : 5 A
MOSFET P-Channel IRF4905 (Q1 et Q2) | RDS(on) = 0.02 Ω Imax = 74 A Compatible pour une alimentation de 12 V
MOSFET N-Channel IRFP044N (Q3 et Q4) | RDS(on) = 0.022 Ω Imax = 57 A
Transistors bipolaires (Q5 et Q6) 2N2222 | VCE(max) = 40 V IC(max) = 800 mA VEB(max) = 6 V β = 100

Simulation du Contrôleur

La conception a été modélisée et simulée avec Proteus. Les résultats ont validé les points

suivants :

— Régulation précise de la vitesse via PWM.

— Contrôle bidirectionnel des moteurs.

— Fonctionnement stable sous différentes charges.

Chapitre 5. Réalisation matérielle | 1. Le contrôleur de moteur

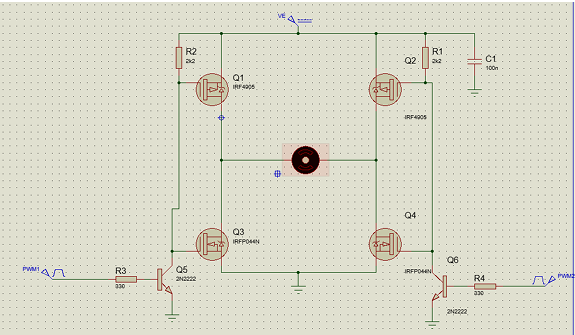
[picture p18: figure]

Figure 5.6 – Simulation : Contrôle bidirectionnel du moteur

Essai du circuit sur plaque d’essai

Avant de lancer le routage du PCB, une première version du circuit a été montée sur une plaque

d’essai (breadboard). Cette étape a permis de tester le fonctionnement global du système de

commande moteur avec les composants principaux : pont en H, ESP32, alimentation et moteurs.

Les essais réalisés ont permis de :

— Vérifier que le contrôle des moteurs via des signaux PWM fonctionnait correctement.

— Tester l’inversion du sens de rotation des moteurs en envoyant des commandes à l’ESP32.

— Tester les alimentations séparées pour l’ESP32 (3.3V) et les moteurs (12V).

Les résultats ont été concluants, car le système répondait aux commandes comme prévu. Cette

phase de validation sur plaque d’essai a permis de confirmer le bon fonctionnement du circuit

avant de procéder à la conception du PCB.

Chapitre 5. Réalisation matérielle | 1. Le contrôleur de moteur

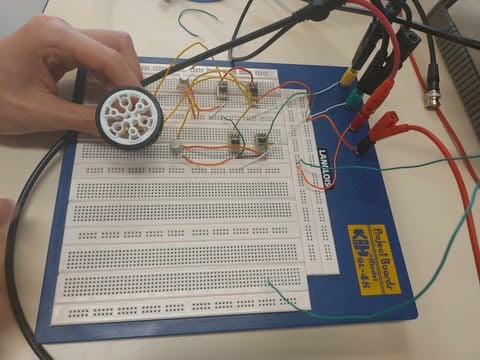
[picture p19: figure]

Figure 5.7 – Essai du circuit de contrôle moteur

### 5.1.3 Routage du PCB sur KiCad

Après validation du schéma électrique, le routage du circuit imprimé a été réalisé à l’aide du

logiciel KiCad. L’objectif était de concevoir un PCB compact, fiable et adapté aux contraintes

de puissance liées au pilotage des moteurs.

Chapitre 5. Réalisation matérielle | 1. Le contrôleur de moteur

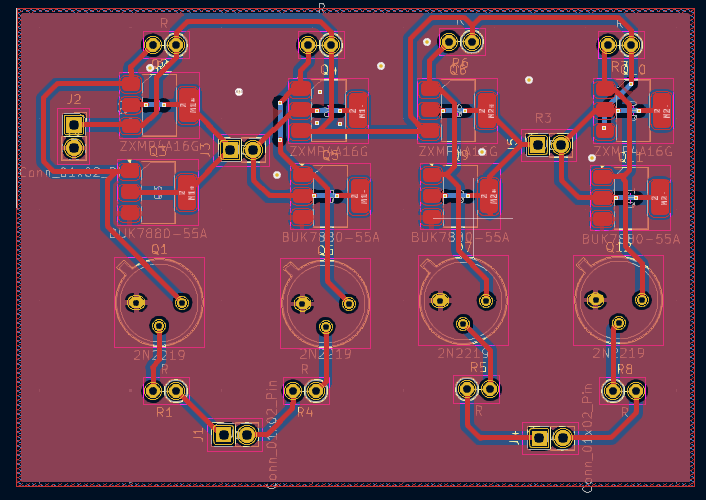
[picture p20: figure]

Figure 5.8 – Routage du PCB sur KiCad

Le placement des composants a été optimisé pour :

— Réduire la longueur des pistes de puissance.

— Limiter les interférences entre les signaux de commande et les circuits de puissance.

— Faciliter les connexions avec les moteurs, l’alimentation et la carte de contrôle.

Des plans de masse ont été ajoutés pour améliorer la stabilité électrique du circuit. Les pistes

d’alimentation ont été élargies pour supporter le courant nécessaire aux moteurs (figure ci-

dessous). Des vias thermiques et des zones de dissipation ont également été prévues autour du

pont en H pour éviter la surchauffe.

Chapitre 5. Réalisation matérielle | 1. Le contrôleur de moteur

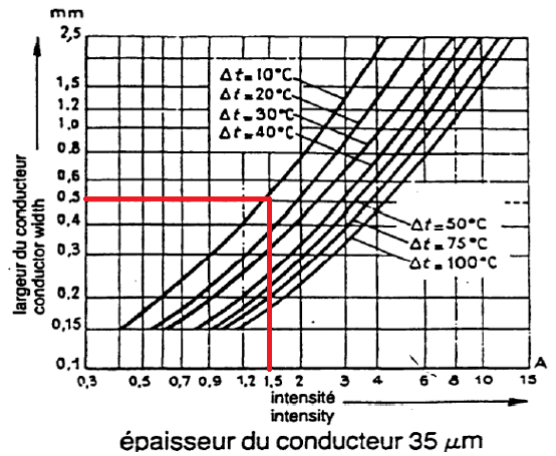
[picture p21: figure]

Figure 5.9 – largeur des pistes

### 5.1.4 Impression du PCB et tests

Une fois le routage terminé, les fichiers Gerber ont été générés pour la fabrication du circuit.

Le PCB a été fabriqué à partir des fichiers Gerber, puis les composants ont été soudés manuel-

lement. Après assemblage, plusieurs tests ont été réalisés :

— Test de continuité pour vérifier l’intégrité des pistes.

— Test de tension sans charge pour contrôler la bonne distribution de l’alimentation.

— Commande moteur via l’ESP32 pour tester les signaux de commande et la réponse des

moteurs.

Chapitre 5. Réalisation matérielle | 1. Le contrôleur de moteur

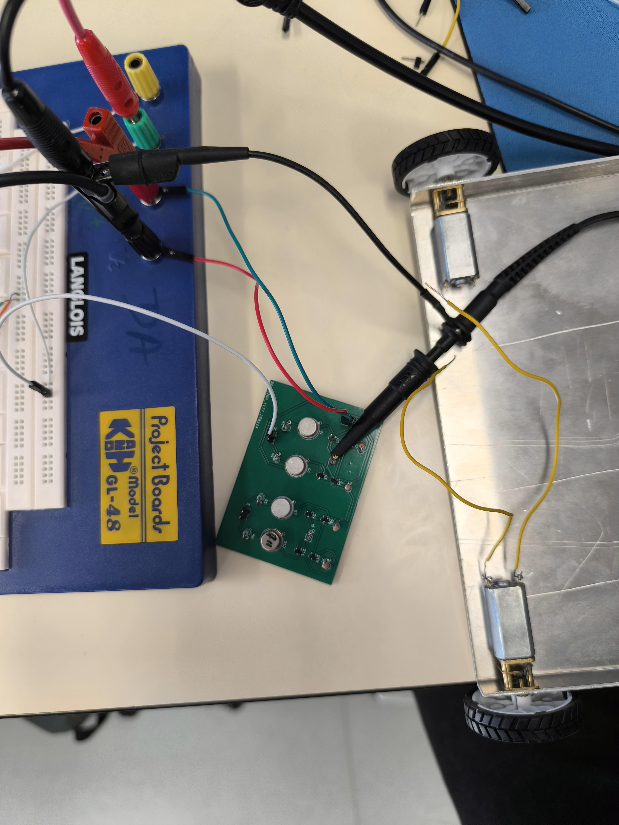
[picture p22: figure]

Figure 5.10 – les tests

Lors des premiers essais, nous avons rencontré un dysfonctionnement au niveau du circuit : les

moteurs ne répondaient pas correctement aux signaux de commande, et certains composants

ne réagissaient pas comme prévu. Après plusieurs vérifications (soudure, connexions, tensions),

il s’est avéré que le problème provenait d’une erreur dans le choix des empreintes .

Une version corrigée du schéma a alors été réalisée. Toutefois, faute de temps, nous n’avons pas

pu imprimer la nouvelle version du PCB avant la fin du projet. Le montage final repose donc

sur la version initiale avec des ajustements manuels, bien que la version corrigée soit prête à

être produite.

Chapitre 5. Réalisation matérielle | 2. Integration des Capteurs et alimentation

## 2 Integration des Capteurs et alimentation

Intégration des Capteurs et Alimentation L’intégration des capteurs et du système d’alimenta-

tion est une étape clé pour assurer la fonctionnalité et l’autonomie de la valise. En combinant

les capteurs nécessaires au suivi et à la détection des obstacles avec un système d’alimentation

efficace, la valise peut fonctionner de manière autonome et réactive.

### 5.2.1 Capteur ultrasonique SH04

Le capteur ultrasonique SH04 a été choisi pour sa capacité à mesurer la distance entre la valise

et les objets qui se trouvent devant elle, permettant ainsi d’éviter les obstacles.

Calcul de la distance

Le calcul de la distance se base sur le principe de la vitesse du son dans l’air. Le temps mesuré

entre l’émission de l’onde et sa réception est multiplié par la vitesse du son, puis divisé par

deux pour obtenir la distance entre le capteur et l’obstacle. La formule est la suivante :

Distance =

Vitesse du sonTemps
2

— Vitesse du son (v) : La vitesse du son dans l’air est généralement considérée comme 343

mètres par seconde (m/s) à température ambiante (20°C).

— Temps (t) : Le temps mesuré par le capteur entre l’émission de l’onde et la réception de son

écho. Ce temps est généralement très court, mesuré en microsecondes (µs).

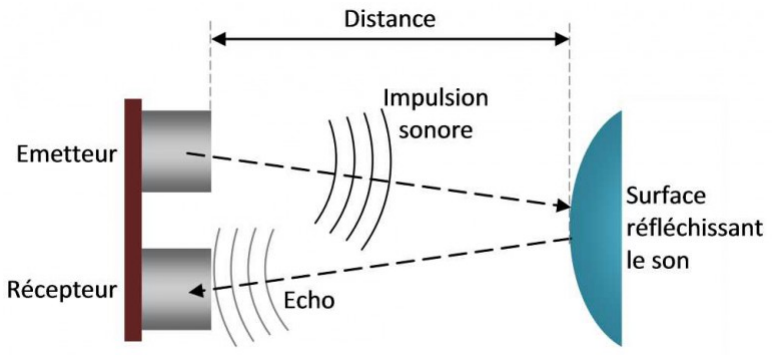
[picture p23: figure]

Cette distance calculée est ensuite utilisée pour déterminer si la valise doit ajuster sa trajectoire

afin d’éviter un obstacle.

Chapitre 5. Réalisation matérielle | 3. Châssis et structure mécanique

Les avantages de ce capteur sont :

— Précision : il offre une bonne précision pour les distances courtes à moyennes.

— Faible consommation d’énergie : il est adapté pour des systèmes alimentés par batterie.

— Simplicité d’intégration : son interface de communication est simple à utiliser avec l’ESP32,

ce qui permet une intégration rapide.

Le capteur SH04 a été positionné à l’avant de la valise pour surveiller son environnement

immédiat et éviter les collisions avec des objets.

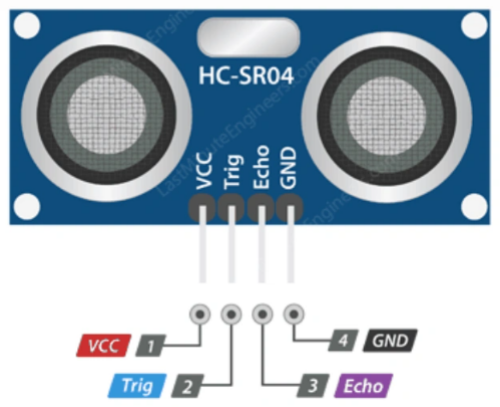
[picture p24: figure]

Figure 5.11 – Capteur ultrasonique SH04

## 3 Châssis et structure mécanique

Le châssis constitue la base physique de la valise autonome, assurant la fixation stable et

sécurisée de l’ensemble des composants matériels : moteurs, capteurs, batteries, carte ESP32 et

contrôleur. Dans ce projet, nous avons conçu un châssis personnalisé en métal, adapté à notre

besoin en termes de robustesse, de stabilité et d’intégration mécanique.

### 5.3.1 Conception et matériau du châssis

Le châssis a été réalisé à partir de plaques métalliques , découpées et assemblées manuellement.

Ce choix de matériau garantit une structure rigide, capable de supporter les vibrations liées au

déplacement et les contraintes mécaniques.

La conception a été guidée par plusieurs critères :

Chapitre 5. Réalisation matérielle | 3. Châssis et structure mécanique

— Résistance mécanique suffisante pour supporter l’ensemble du système (batterie, moteurs,

capteurs, électronique),

— Stabilité dynamique pendant les phases de déplacement,

— Facilité de fixation pour les composants avec perçage ou vissage direct,

— Format compact et optimisé pour respecter l’encombrement d’une valise réelle.

### 5.3.2 Dimensionnement et implantation des composants

Les dimensions globales du châssis ont été fixées à :

— 300 mm (longueur) × 200 mm (largeur).

La disposition des composants a été pensée pour équilibrer les masses et optimiser les perfor-

mances :

— Batterie : placée au centre pour une meilleure répartition du poids.

— ESP32 et contrôleur moteur : positionnés à l’arrière, à proximité des moteurs, afin de

réduire la longueur des câbles de puissance.

— Capteurs ultrasoniques : fixés à l’avant pour maximiser la couverture de détection d’obs-

tacles.

— Moteurs DC : montés à l’arrière sur des supports métalliques prévus à cet effet.

— Roues avant : fixes ou pivotantes selon les essais réalisés, placées à l’avant du châssis.

## Conclusion

La conception du contrôleur de moteur, associée à un dimensionnement précis des composants,

a permis de garantir une commande efficace et sécurisée des moteurs. La simulation a validé

le bon fonctionnement du circuit avant la réalisation du PCB. L’intégration des capteurs et de

l’alimentation assure une autonomie et une réactivité adaptées aux besoins de la valise. Cette

étape constitue une base technique solide pour le déplacement autonome du système.

# Conclusion générale

Ce projet de valise autonome connectée s’inscrit dans une démarche d’innovation visant à amé-

liorer la gestion des bagages et la sécurité lors des déplacements. Il repose sur l’interaction entre

un système embarqué (ESP32), des capteurs physiques, une logique de navigation intelligente,

et une application mobile Flutter.

Tout au long du développement, nous avons été confrontés à divers problèmes techniques :

instabilité du protocole TCP, variations imprévisibles du signal RSSI, imprécisions du capteur

ultrasonique, incompatibilité des bibliothèques, ou encore difficultés dans la fabrication du

circuit imprimé du contrôleur moteur. Pour chaque obstacle rencontré, nous avons trouvé une

solution adaptée, comme l’intégration d’une tolérance entre la mesure RSSI et la distance

capteur, ou le passage à une communication HTTP plus stable.

Malgré les nombreuses difficultés rencontrées, nous avons tout de même réussi à faire fonctionner

plusieurs parties essentielles du projet. Bien que le prototype complet ne soit pas finalisé, nous

avons pu tester et valider des fonctionnalités clés telles que la communication entre l’ESP32 et

l’application Flutter, l’estimation de la distance via le RSSI, ainsi que la détection d’obstacles.

Ce projet nous a permis d’acquérir des compétences solides et variées :

— Côté logiciel :

— Développement d’une application Flutter communicant avec un microcontrôleur,

— Intégration d’une logique de traitement des données, de gestion d’état et d’affichage

en temps réel,

— Implémentation d’un serveur HTTP sur ESP32 avec traitement des requêtes JSON,

— Test et adaptation du RSSI pour estimer la distance.

— Côté matériel :

Chapitre 5. Réalisation matérielle | 3. Châssis et structure mécanique

— Programmation embarquée (capteurs, moteur, logique de navigation),

— Simulation, prototypage et test du contrôleur moteur,

— Conception et routage du PCB via KiCad,

— Intégration d’une logique de détection d’obstacle avec marge de tolérance.

— Compétences transversales :

— Gestion de projet (diagrammes de Gantt, répartition des tâches),

— Capacité à faire face à des imprévus techniques,

— Documentation, collaboration et présentation du projet en démonstration réelle.

Sur le plan personnel, ce projet nous a appris à collaborer efficacement, à documenter rigou-

reusement chaque étape, et à ne pas sous-estimer l’importance des tests en conditions réelles.

Si c’était à refaire, nous structurerions l’application Flutter avec un modèle MVVM complet

dès le début, et nous anticiperions davantage les contraintes liées à la conception du PCB pour

éviter les erreurs de composants ou de routage.

En conclusion, ce projet a été une aventure technique, humaine et pédagogique. Il nous a

permis de mettre en pratique nos acquis tout en développant des compétences nouvelles dans

un contexte concret, riche en enseignements. Il représente pour nous une étape importante dans

notre préparation au monde professionnel.

# Bibliographie

[1] ForwardX Ovis – Valise autonome basée sur l’IA et la caméra.

Disponible sur : https://www.forwardx.com/ovis/ [Consulté le 16 Décembre 2024].

[2] Travelmate Robotics – Valise autonome avec Bluetooth RSSI.

Disponible sur : https://travelmate.robotics/ [Consulté le 16 Décembre 2024].

[3] Cowarobot R1 – Valise autonome utilisant des capteurs ultrasoniques et LiDAR.

Disponible sur : https://www.cowarobot.com/ [Consulté le 16 Décembre 2024].

[4] Capteur ultrasonique HC-SR04 – Détection d’obstacles.

Disponible sur : https://www.gotronic.fr/art-module-de-detection-us-hc-sr04-20912.htm

[Consulté le 16 Décembre 2024].

[5] NodeMCU ESP32 – Microcontrôleur compact avec Wi-Fi et Bluetooth.

Disponible sur : https://www.gotronic.fr/art-module-nodemcu-esp32-28407.htm [Consulté

le 16 Décembre 2024].

[6] Paire de roues FIT0494 – Accessoires pour robotique.

Disponible sur : https://www.gotronic.fr/art-paire-de-roues-fit0494-37019.htm [Consulté

le 16 Décembre 2024].

# Résumé

Dans ce rapport, nous avons présenté notre avancement dans le projet qui concerne la conception

et la réalisation d’une valise autonome capable de suivre son propriétaire . Ce travail inclut une

partie de gestion de projet, l’étude de l’environnement, l’architecture du projet, et finalement

la réalisation.

Mots clés : Valise autonome, Navigation intelligente, Gestion de projet, Étude de l’en-

vironnement, Architecture, Réalisation.

# Abstract

In this report, we present our progress on the project concerning the design and implementation

of an autonomous suitcase capable of following its owner . This work includes a project mana-

gement section, an environment study, the system architecture, and finally the implementation.

Keywords : Autonomous suitcase, Intelligent navigation, Project management, Envi-

ronment study, Architecture, Implementation.

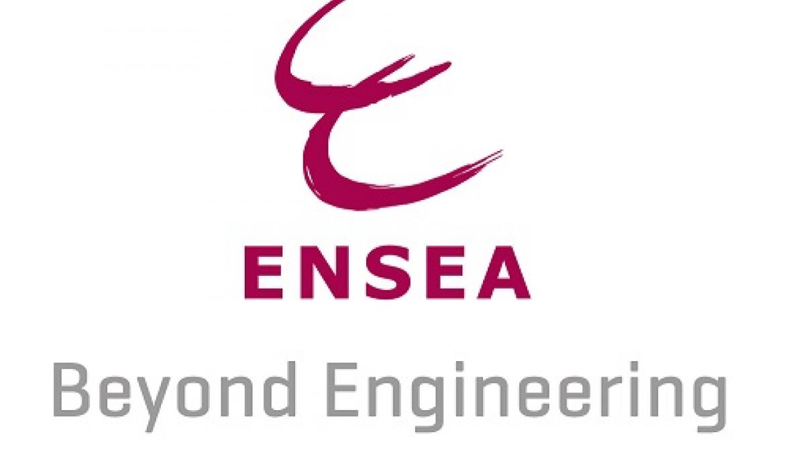
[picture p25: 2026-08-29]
mobile-app/assets/images/background.jpg

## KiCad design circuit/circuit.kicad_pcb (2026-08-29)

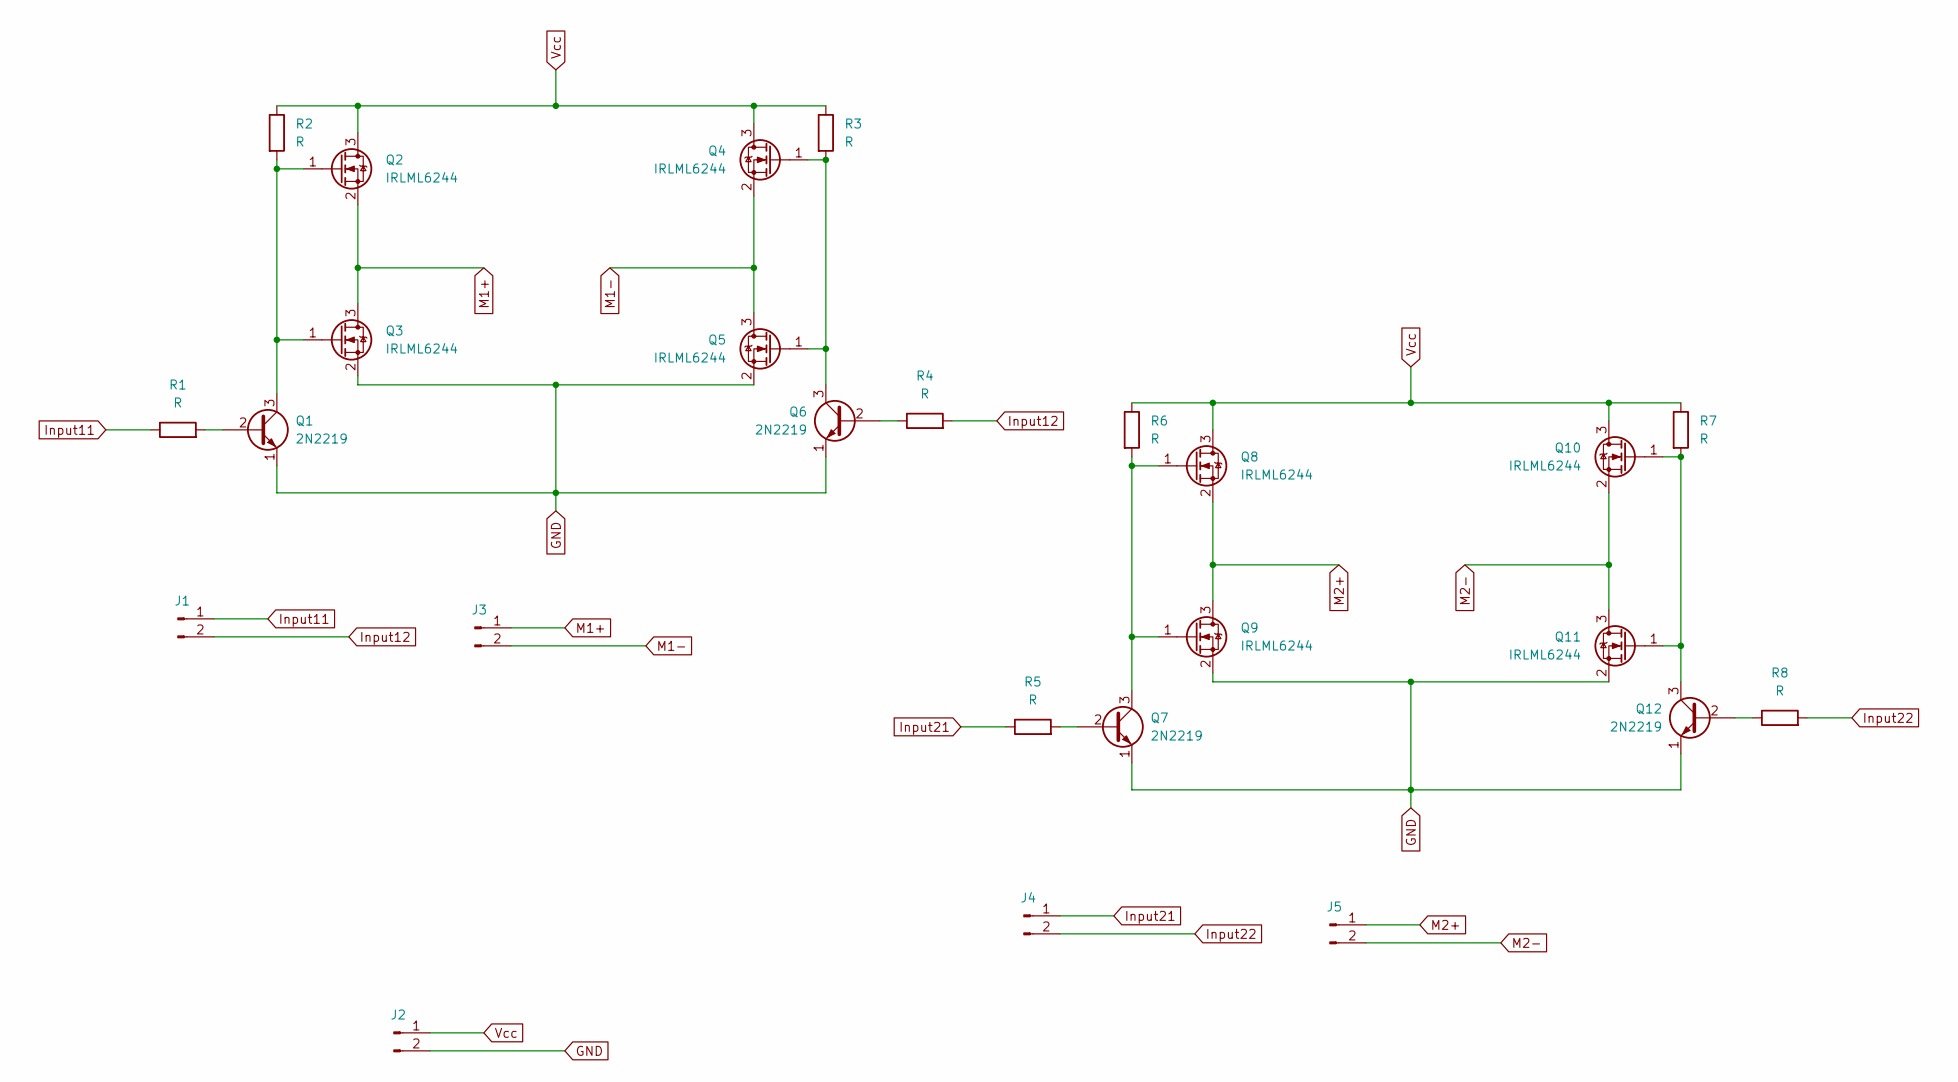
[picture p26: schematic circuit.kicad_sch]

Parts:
J1, J2, J3, J4, J5: Conn_01x02_Pin; PinSocket_1x02_P2.54mm_Vertical
Q1, Q6, Q7, Q12: 2N2219; TO-39-3
Q2, Q3, Q4, Q5, Q8, Q9, Q10, Q11: IRLML6244; SOT-23
R1, R2, R3, R4, R5, R6, R7, R8: R; R_Axial_DIN0207_L6.3mm_D2.5mm_P2.54mm_Vertical

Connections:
GND: J2.2, Q1.1 (E), Q3.2 (S), Q5.2 (S), Q6.1 (E), Q7.1 (E), Q9.2 (S), Q11.2 (S), Q12.1 (E)
Input11: J1.1, R1.1
Input12: J1.2, R4.2
Input21: J4.1, R5.1
Input22: J4.2, R8.2
M1+: J3.1, Q2.2 (S), Q3.3 (D)
M1-: J3.2, Q4.2 (S), Q5.3 (D)
M2+: J5.1, Q8.2 (S), Q9.3 (D)
M2-: J5.2, Q10.2 (S), Q11.3 (D)
unnamed: Q1.2 (B), R1.2
unnamed: Q1.3 (C), Q2.1 (G), Q3.1 (G), R2.2
unnamed: Q4.1 (G), Q5.1 (G), Q6.3 (C), R3.2
unnamed: Q6.2 (B), R4.1
unnamed: Q7.2 (B), R5.2
unnamed: Q7.3 (C), Q8.1 (G), Q9.1 (G), R6.2
unnamed: Q10.1 (G), Q11.1 (G), Q12.3 (C), R7.2
unnamed: Q12.2 (B), R8.1
Vcc: J2.1, Q2.3 (D), Q4.3 (D), Q8.3 (D), Q10.3 (D), R2.1, R3.1, R6.1, R7.1

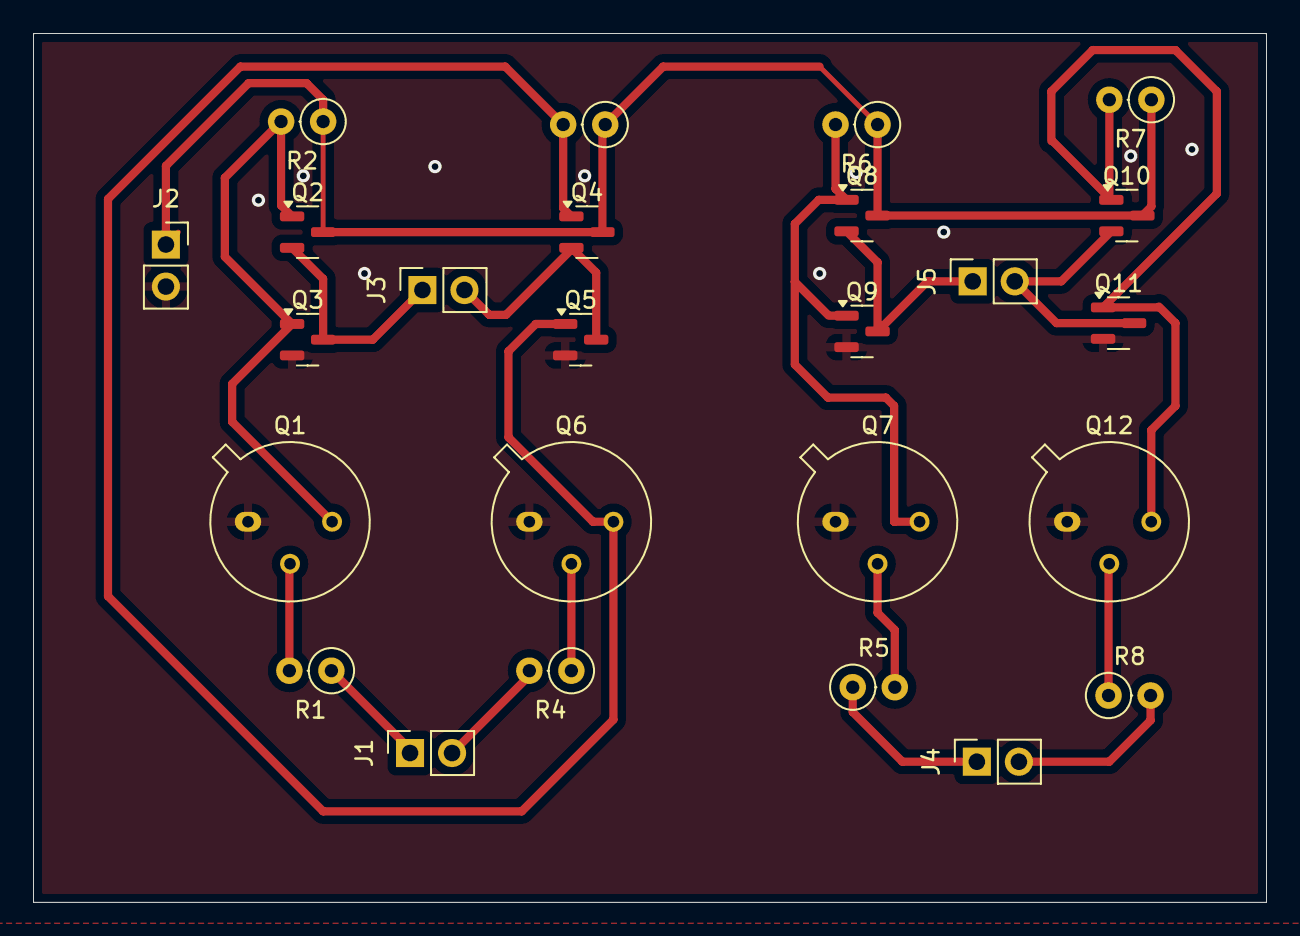
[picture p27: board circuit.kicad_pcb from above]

Board: 2 copper layers, 74.5 x 52.5 mm, 25 parts (0 on the bottom side), 18 nets.

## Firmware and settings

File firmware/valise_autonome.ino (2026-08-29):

#include <WiFi.h>
#include <WebServer.h>
#include <esp_wifi.h>

// Wi-Fi credentials (AP mode)
const char *ssid = "Suitcase_AP";
const char *password = "12345678";

WebServer server(80); // HTTP server on port 80

// Ultrasonic sensor pins
#define TRIG_FRONT 4
#define ECHO_FRONT 2

const float TOLERANCE = 15.0; // in cm

// === Init ultrasonic pins ===
void initUltrasonic() {
  pinMode(TRIG_FRONT, OUTPUT);
  pinMode(ECHO_FRONT, INPUT);
}

// === Measure distance using ultrasonic sensor ===
float mesurerDistance() {
  digitalWrite(TRIG_FRONT, LOW);
  delayMicroseconds(5);
  digitalWrite(TRIG_FRONT, HIGH);
  delayMicroseconds(10);
  digitalWrite(TRIG_FRONT, LOW);

  long duration = pulseIn(ECHO_FRONT, HIGH, 30000);  // timeout = 30ms
  if (duration == 0) return -1;  // No echo

  float distance = duration * 0.034 / 2;  // cm
  return distance;
}

// === Handle GET /status ===
void handleStatus() {
  wifi_sta_list_t stationList;
  String message = "No devices connected";
  float rssiDistance = 0;
  float obstacleDistance = -1;

  if (esp_wifi_ap_get_sta_list(&stationList) == ESP_OK) {
    if (stationList.num > 0) {
      int rssi = stationList.sta[0].rssi;
      rssiDistance = pow(10, (-50 - rssi) / (10 * 2.0)) * 100; // in cm

      obstacleDistance = mesurerDistance();  // Measure distance using ultrasonic sensor
    }
  }

  // Logic for real obstacle detection: if obstacle distance is smaller than RSSI distance
  bool isRealObstacle = (obstacleDistance > 0 && obstacleDistance < rssiDistance);

  // Create JSON response with status, RSSI-based distance, and obstacle distance (only send if real obstacle)
  String jsonResponse = "{";
  jsonResponse += "\"status\": \"connected\","; // assume always connected for simplicity
  jsonResponse += "\"rssi_distance\": " + String(rssiDistance) + ",";

  // Only send obstacle distance if it's a real obstacle
  if (isRealObstacle) {
    jsonResponse += "\"obstacle_distance\": " + String(obstacleDistance);
  } else {
    jsonResponse += "\"obstacle_distance\": -1";  // Indicate no real obstacle
  }

  jsonResponse += "}";

  // Allow CORS for Flutter Web
  server.sendHeader("Access-Control-Allow-Origin", "*");
  server.sendHeader("Access-Control-Allow-Methods", "GET");
  server.sendHeader("Access-Control-Allow-Headers", "Content-Type");

  server.send(200, "application/json", jsonResponse);  // Send JSON response
}

// === Setup ===
void setup() {
  Serial.begin(115200);

  // Start Wi-Fi in Access Point mode
  WiFi.softAP(ssid, password);
  Serial.println("✅ ESP32 Access Point started!");
  Serial.print("📡 IP Address: ");
  Serial.println(WiFi.softAPIP());

  initUltrasonic();

  // Setup HTTP route
  server.on("/status", handleStatus);
  server.begin();
  Serial.println("🌐 Web server started.");
}

// === Loop ===
void loop() {
  // Handle incoming HTTP requests
  server.handleClient();

  // Continuously measure and log RSSI and obstacle distance to serial monitor
  wifi_sta_list_t stationList;
  float rssiDistance = 0;
  float obstacleDistance = -1;

  if (esp_wifi_ap_get_sta_list(&stationList) == ESP_OK) {
    if (stationList.num > 0) {
      int rssi = stationList.sta[0].rssi;
      rssiDistance = pow(10, (-50 - rssi) / (10 * 2.0)) * 100; // in cm

      obstacleDistance = mesurerDistance();  // Measure distance using ultrasonic sensor
    }
  }

  // Log data to serial monitor
  Serial.print("📶 RSSI: ");
  Serial.print(rssiDistance);
  Serial.print(" cm  |  Obstacle Distance: ");
  Serial.print(obstacleDistance);
  Serial.println(" cm");

  delay(1000); // Update every second
}
